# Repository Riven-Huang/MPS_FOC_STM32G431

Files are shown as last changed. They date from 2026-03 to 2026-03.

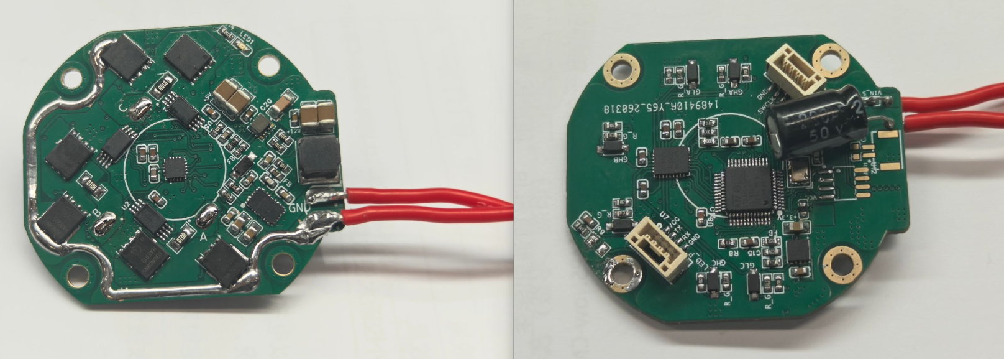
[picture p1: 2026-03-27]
docs/images/hardware_double.png

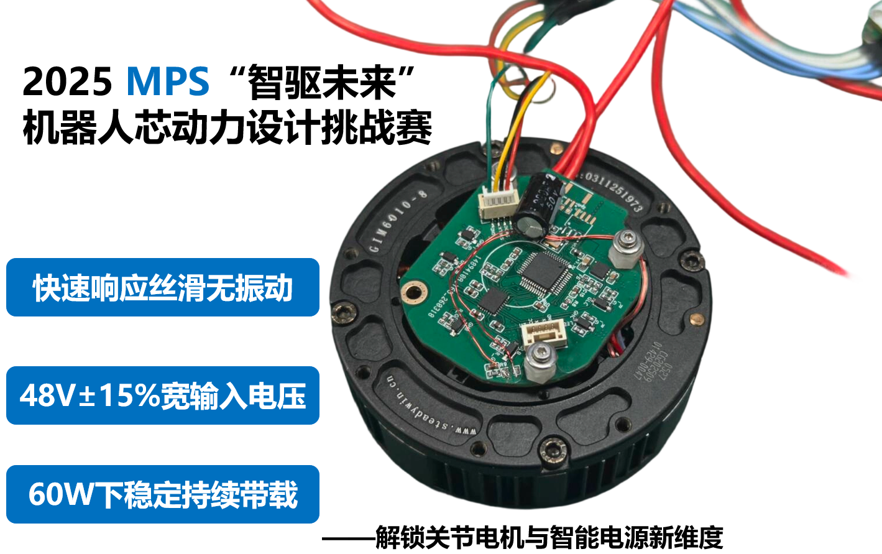
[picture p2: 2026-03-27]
docs/images/poster_done.png

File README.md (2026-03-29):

<div align="center">

# MPS-FOC STM32G431

### 开源无刷电机 FOC 控制工程 | Open-Source PMSM / BLDC FOC Project

<p>
  
  
  
  
  
</p>

</div>

> 注意，刚说明针对LCEDA项目下的V1.2版本，其余版本为F280023C下设计，未提供程序源码。V1.2为三环闭环完整的STM32G431CBT6所设计

## 目录

- [1. 项目简介](#sec-1-overview)
- [2. MPS大学计划](#sec-2-mps)
- [3. 验收测试与视频](#sec-3-test)
- [4. 硬件说明](#sec-4-hardware)
- [5. 软件架构](#sec-5-software)
- [6. 控制实现说明](#sec-6-control)
- [7. 快速开始](#sec-7-quickstart)
- [8. 项目目录](#sec-8-tree)
- [9. 已知限制与后续计划](#sec-9-plan)
- [10. 相关文件](#sec-10-files)
- [11. 许可证说明](#sec-11-license)

---

## 1. 项目简介

### 1.1 项目定位

本项目基于 `STM32G431CBT6`，面向 `PMSM / BLDC` 的三相 FOC 控制。仓库目标是提供一套可直接落到板级 bring-up 的开源实现。

适用场景：

- 板子已经打样完成，需要尽快确认“代码怎么烧录、上电后怎么先转起来”。
- 正在做自研 FOC 控制板，需要参考一套完整的“采样 -> 快环 -> 慢环 -> telemetry -> 调参”工程结构。

### 1.2 当前工程状态

当前仓库已经具备完整主链路，不是只有框架：

- 当前工程实现了所有MPS-FOC比赛中的所有测试项目，该项目为开源广场LCEDA中的**V1.2版本**(<mark>一定注意！！！</mark>)，仅仅V**1.2版本**是STM32G431制作，其余系列为TI的F280025C DSP系列下进行迭代产物。

---

## 2. MPS大学计划

### 2.1 申请说明

MPS 中国大学计划面向高校教学、科研与竞赛项目，适合本项目所用电机控制相关器件申请。若需要 `MP6539B`、`MA600A`、`MIE1W0505`、`MP4583`、`MPM3632S`、`MP20051` 等样片，可通过对应入口申请。

- 在校大学生：使用 [MPS大学计划](https://www.monolithicpower.cn/cn/support/mps-cn-university.html)
- 非在校个人开发者：使用 [MPSNOW](https://www.monolithicpower.cn/cn/support/mps-now.html)
- 申请备注：`MPS-competition-FOC`

### 2.2 二维码入口

<p align="center">
  MPS University Program QR
</p>

---

## 3. 验收测试与视频

本节将仓库内已经公开的验收项、测试视频与现有数据集中整理，便于开源发布时快速核对。当前能够直接在仓库中举证的量化结果包括：

- `48V ±15%` 宽输入电压
- `60W` 下稳定持续带载
- 一系列基础测试项
- `180W`下带载情况与热测量

### 3.1 验收测试总表

| # | 验收项目 | 参考验收标准 | 测试数据 | 数据来源 |
| --- | --- | --- | --- | --- |
| 1 | 电源输入范围测试 | `48V ±15%` 宽输入电压 | 40V-56V宽输入运行 | 视频：Test1 Power Supply  Input Voltage Range Test.mp4 |
| 2 | 启停性能测试 | 空载测试，目测电机启动是否丝滑无振动 | 见视频运行结果 | 视频：Test2 StartStop Performance.MP4 |
| 3 | 速度控制精度测试 | 目标转速100RPM、200RPM, 通过MA600A寄存器读对应速度值 | 测试报告记录：电机减速箱后出轴端 `100 rpm`下扰动`3rpm`、输出轴 `200 rpm` 下，`8rpm` | 视频：Test3 Speed Control Accuracy.MP4 |
| 4 | 位置控制精度测试 | 目标角度90°、180°, 通过MA600A寄存器读对应角度值 | 几乎无误差 | 视频：Test4 Position Control Accuracy |
| 5 | 负载输出能力测试 | 带载持续运行，可结合实际情况选择验证方式<br/> 1.通过10cm力臂实际带载2kg，验证可支持≥6A相电流<br/> 2. R+L模型模拟: 负载星型连接，每相取3Ω+200μH<br/>HSA=L, LSA=H；HSC=L, LSC=H<br/>HSB=20khz PWM 62% 占空比，LSB 与其互补； <br/>测量该条件下IOUTB或48V母线侧电流大小 | 当该项目等效功率60W等级。本仓库对于60W等级和180W等级分别进行了测试，详情可见下面说明。 | 视频：LoadTEST.MP4 |
| 6 | 负载输出能力补充测试 | 10cm力臂，2kg负载，48Vbus 265rpm下连续运行30分钟，测量电机NTC热敏电阻(10K 3950)对应阻值 | 同上 | 视频：LoadTEST.MP4 |

### 3.2 单项测试数据

3.2.1 电源输入测试

略

3.2.2 启停性能测试

略

3.2.3 速度控制精度测试



如上图所示为速度控制时的精度与扰动，图示的数据为电机出轴端之前的机械转速RPM。

3.2.4 位置控制精度



如图所示，几乎无误差

3.2.5

测试平台如下图，准备了两个一样的电机，一个电机作为驱动，另一个作为发电机，通过增程器整流输出到电子负载。



负载输出测试，如图所示。可以参考视频，在180W情况下持续带载运行(赛题要求的功率等级是60W等级)，运行2mins时温度如下图



运行8mins后，壳温来到了74℃，板上最热点为82.9℃。

---

## 4. 硬件说明

### 4.1 硬件实物图





### 4.2 硬件核心配置

| 🧩 模块  | 📦 当前实现 | 📝 说明 |
| --- | --- | --- |
| 主控 MCU | `STM32G431CBT6` | 170 MHz，带高级定时器，适合 FOC 快环  |
| PWM 输出 | `TIM1 CH1/2/3 + CH1N/2N/3N` | 中心对齐、互补输出、带死区 |
| 功率级使能  | `N_SLEEP` | 控制驱动器休眠 / 使能 |
| 故障输入 | `N_FAULT` | 当前用于驱动器故障检测 |
| 电流采样 | `ADC1_IN1 / IN3 / IN4` | 三相独立采样，注入组同步触发 |
| 母线采样 | `ADC2_IN12` | `VBUS` |
| 温度采样 | `ADC2_IN14` | `NTC` |
| 编码器 | `MA600A + SPI1` | 16-bit 绝对值角度反馈 |
| 调试串口 | `USART1 + DMA TX` | VOFA / JustFloat 波形输出 |
| 预驱动芯片  | `MP6539B` | 3 相 N+N 半桥预驱动，支持 100% 占空比 |
| 升降压芯片  | `MP4583` | 宽输入电压 DCDC，支持 48V 总线 |
| 栅极驱动供电 | `MIE1W0505` | 隔离 DC-DC，为预驱动提供隔离供电 |
| POL 供电 | `MPM3632S` | 3.3V/3A POL，为 MCU 和编码器供电  |
| 备份供电 | `MP20051` | LDO，为 MCU 待机部分供电 |

### 4.3 电机与机构默认参数

当前默认参数位于 [`program/App/motor_params.h`](program/App/motor_params.h)：

| ⚙️ 参数 | 当前值  | 说明 |
| --- | ---- | --- |
| 极对数 | `14` | `MOTOR_POLE_PAIRS` |
| 减速比 | `8`  | `MOTOR_GEAR_RATIO` |
| 编码器方向 | `-1` | `MOTOR_ENCODER_DIRECTION_SIGN` |
| 编码器安装位置 | 转子侧  | `MOTOR_ENCODER_ON_OUTPUT_SHAFT = 0` |

## 5. 软件架构

### 5.1 软件结构图

<p align="center">
  Software Architecture
</p>

### 5.2 控制流程图

<p align="center">
  Control Flow
</p>

### 5.3 代码组织

| 📁 目录 / 文件 | 🧠 职责 |
| --- | --- |
| `program/Core/` | HAL 初始化、IRQ、CubeMX 生成外设配置 |
| `program/App/program.c` | 当前真实控制主链路、快慢环调度、保护、telemetry |
| `program/App/foc_core.c` | Clarke / Park / 反 Park / SVPWM  |
| `program/App/ma600a.c` | MA600A 绝对值编码器驱动 |
| `program/App/filter.c` | 一阶低通滤波器 |
| `program/App/cli_uart.c` | VOFA / DMA 串口发送 |
| `program/App/drv_pid.c` | 通用 Q15 PI 组件，当前不在 10 kHz 热路径主链里 |
| `program/App/motor_state.c` | 状态对象与保留状态机逻辑 |
| `docs/` | 补充说明、调试文档、图像资源 |

---

## 6. 控制实现说明

### 6.1 控制流程说明：从 ADC 采样到 PWM 输出

当前工程的实际控制链路如下：

1. `TIM1` 输出中心对齐 PWM，并通过 `TRGO2 = UPDATE` 触发 `ADC1 injected`。
2. `ADC1` 一次完成 `IA / IB / IC` 三路电流采样。
3. 在 `HAL_ADCEx_InjectedConvCpltCallback()` 中读取三相原始值。
4. 启动阶段累计 `1024` 个样本，得到每相零偏。
5. 同步调度 `MA600A` 读角，更新机械角、电角度和测速窗口。
6. 原始电流码值转换为安培值，并做一阶低通。
7. 执行 `Clarke / Park`，得到 `id / iq`。
8. 位置环按 `100 Hz` 分频运行，输出机械速度参考。
9. 速度环按测速窗口更新运行，输出 `iq_ref` 或 `uq_ref`。
10. 电流环按 `10 kHz` 运行，输出 `ud_ref / uq_ref`。
11. 反 `Park` 后进入 `SVPWM`。
12. 将 `duty_a / duty_b / duty_c` 写入 `TIM1->CCR1/2/3`。

### 6.2 中断结构 / 控制周期

快环入口调用链：

```text
ADC1_2_IRQHandler
  -> HAL_ADC_IRQHandler(&hadc1)
    -> HAL_ADCEx_InjectedConvCpltCallback()
      -> program_adc_injected_conv_cplt_callback()
```

慢环入口调用链：

```text
TIM6_DAC_IRQHandler
  -> HAL_TIM_IRQHandler(&htim6)
    -> HAL_TIM_PeriodElapsedCallback()
```

当前工程对应的运行频率：

| ⏱️ 项目 | 当前值 | 触发源 / 说明 |
| --- | --- | --- |
| PWM 载波 | 约 `20 kHz`  | `TIM1 center-aligned + ARR=4249 + RCR=3` |
| 电流环 | `10 kHz` | `ADC1 injected` 完成回调 |
| 位置环 | `100 Hz` | 快环分频 |
| 速度测速窗口 | `20` 个快环样本  | `PROGRAM_SPEED_OBSERVER_WINDOW_SAMPLES`  |
| 速度环有效更新率 | 名义 `500 Hz` | 由测速窗口更新驱动 |
| 慢任务节拍 | `1 kHz` | `TIM6` 中断 + `TIM6 TRGO -> ADC2` |

慢环主要处理：

- `ADC2 + DMA` 采集 `VBUS / NTC`
- `program_task()` 在 `while(1)` 中按 `TIM6` 节拍执行后台任务和遥测输出

### 6.3 速度环与测速观测器

（内容待补充）

### 6.4 位置环实现

（内容待补充）

### 6.5 状态机与启动时序

（内容待补充）

### 6.6 Telemetry 变量设计

当前统一观测对象是：

```c
extern volatile program_telemetry_t g_program_telemetry;
```

该对象的职责不是“只拿来画波形”，而是把 bring-up 所需的事实状态统一汇总到一个对象里。这样做有两个直接好处：

- 调试器观察和 VOFA 输出共用同一套字段。
- 采样层、控制层、命令层、状态层不再散落成多个临时全局变量。

| 📊 层级 | 典型字段 | 作用 |
| ----- | --- | --- |
| 原始采样层 | `ia_raw` `ib_raw` `ic_raw` `vbus_raw` | 查 ADC、偏置和量程问题 |
| 工程量层  | `ia` `ib` `ic_meas` `id` `iq` `theta_elec` | 查控制量是否正确 |
| 命令层 | `id_ref_cmd` `iq_ref_cmd` `ud_ref_cmd` `uq_ref_cmd` | 查参考值链路是否正确传递  |
| 运行状态层 | `control_state` `driver_fault_active` `fast_loop_time_us` | 查状态机与实时性 |

如果你习惯把这个对象命名为 `g_motor_telemetry`，角色是一样的；但当前仓库实际实现以 `g_program_telemetry` 为准。

---

## 7. 快速开始

此处重点关注变量g_motor,控制参数结构体

### 7.1 开发环境

- IDE：Keil / MDK
- 工程文件：[`program/MDK-ARM/STM32G431_FOC.uvprojx`](program/MDK-ARM/STM32G431_FOC.uvprojx)
- CubeMX 工程：[`program/STM32G431_FOC.ioc`](program/STM32G431_FOC.ioc)
- 下载方式：CMSIS-DAP Debugger

### 7.2 程序上电后自动完成的内容

- `ADC1 / ADC2` 校准
- `TIM1` PWM 启动并保持 `50%` 占空比
- 三相电流零偏累计
- `ADC2 DMA` 开始采集 `VBUS / NTC`
- `MA600A` 首次读角

### 7.3 第一次跑起来的推荐配置

建议第一次出力先不要直接上速度环，而是先做开环电压测试：

```c
g_motor.current_loop_enable = 0;
g_motor.speed_loop_enable = 0;
g_motor.position_loop_enable = 0;
g_motor.ud_ref = 0.0f;
g_motor.uq_ref = 0.5f;   /* 从小值开始 */
g_motor.run_request = 1;   /*  最核心的启动信号，启动这个才开始运行发波 */
```

程序会先自动做对齐，再进入基于编码器角度的手动电压模式。

### 7.4 模式控制说明

该版本program一共有四个模式控制变量，与一个运行启动控制变量。其中每个模式变量负责一个环路，运行启动变量负责整个系统的使能。

```c
g_motor.current_loop_enable = 0; /* 是否用电流环控制，若失能则跑开环电压*/
g_motor.speed_loop_enable = 0;  /* 是否用速度环控制，若失能则单电流环或开环电压*/
g_motor.position_loop_enable = 0;/* 位置环，需使能速度环使用，否则无效果*/
g_motor.
g_motor.run_request = 1;   /*  最核心的启动信号，启动这个才开始运行发波 */
```

各个模式调试时，可以再继续看g_motor内部的ref变量，使能对应控制环的时候，需要手动给定对应的ref变量。

### 7.5 首次需要看的变量

| 👀 变量 | 正常现象 |
| --- | --- |
| `current_offset_ready` | 上电后置位 |
| `ia / ib / ic_meas` | 静止时接近 `0` |
| `i_abc_sum` | 接近 `0` |
| `ma600a_angle_rad` | 手动转动时连续变化 |
| `driver_fault_active`  | `0` |
| `fast_loop_overrun` | `0` |

### 7.6 三环由内到外的闭环调试顺序

不要跳步，建议严格按“由内到外”执行：

| 阶段 | 🎯 目标  | 🔧 推荐配置 | 👀 重点观察 |
| --- | --- | --- | --- |
| Stage 0 | 静态链路确认 | `run_request = 0` | `ia/ib/ic` `vbus` `ma600a_angle_rad` |
| Stage 1 | 验证出力方向 | 关速度环、关位置环 | `uq_ref` `theta_elec` |
| Stage 2 | 调电流环 | 开电流环，关外环 | `id` `iq` `ud_ref_cmd` `uq_ref_cmd` |
| Stage 3 | 调速度环 | 开速度环，位置环保持关闭 | `speed_ref_mech_rpm` `speed_meas_mech_rpm` |
| Stage 4 | 调位置环 | 最后再开位置环 | `position_ref_mech_rad` `position_meas_mech_rad` |

### 7.7 当前运行默认参数

以下为当前主路径实际生效的默认参数，来源于 [`program/App/program.c`](program/App/program.c)：

电流环带宽计算，可以看代码注释，当前电流环带宽为1Khz。

| 🧪 参数 | 当前值 |
| --- | --- |
| `current_kp`  | `2.5761`  |
| `current_ki`  | `4555.31` |
| `speed_kp` | `0.003` |
| `speed_ki` | `0.03` |
| `position_kp` | `3.0` |
| `position_ki` | `0.0` |
| `iq_limit` | `8.0 A` |

更详细的 bring-up 和三环调试步骤见 [`docs/quick-start.md`](docs/quick-start.md)。

---

## 8. 项目目录

```text
.
|-- README.md
|-- LICENSE
|-- circurit/                    # 原理图、器件手册、Gerber（目录名沿用当前仓库拼写）
|-- docs/
|   |-- quick-start.md           # 快速开始与三环调试说明
|   |-- figures/                 # 软件架构图、控制流程图
|   `-- images/                  # README 图片资源
|-- experiment/
|   |-- photo/                   # 波形截图、VOFA 截图、实拍图
|   |-- video/                   # 单项测试视频
|   `-- 测试报告.docx
`-- program/
    |-- STM32G431_FOC.ioc        # CubeMX 工程
    |-- Core/                    # HAL / IRQ / CubeMX 生成代码
    |-- App/                     # 控制算法与项目逻辑
    `-- MDK-ARM/                 # Keil 工程
```

---

## 9. 已知限制与后续计划

### 9.1 当前已确认的限制

- MA600A角度反馈链路，应当存在一定问题，导致速度环目前有一个波动始终存在，且1/4倍于电机机械转速，也就是2倍于电机出轴端的转速。
- 目前MA600A的反馈链路未做INL校准。

---

## 10. 相关文件

- [快速开始与三环调试文档](docs/quick-start.md)
- [软件结构图](docs/figures/software-architecture.svg)
- [控制流程图](docs/figures/control-flow.svg)
- [CubeMX 工程](program/STM32G431_FOC.ioc)
- [Keil 工程](program/MDK-ARM/STM32G431_FOC.uvprojx)
- [测试报告](experiment/%E6%B5%8B%E8%AF%95%E6%8A%A5%E5%91%8A.docx)
- [实验图片目录](experiment/photo)
- [实验视频目录](experiment/video)

---

## 11. 许可证说明

本项目基于 **GNU General Public License v3.0 (GPL 3.0)** 开源许可协议发布。

详细内容请参阅本仓库根目录下的 [`LICENSE`](LICENSE) 文件。

### 概要

- **允许**：自由使用、修改、商业衍生
- **要求**：衍生作品必须同样以 GPL 3.0 发布，并保留源码
- **禁止**：不以任何方式提供源码

### 引用方式

```text
MPS-FOC STM32G431
Copyright (C) 2026 MPS China University Program
This program is free software: you can redistribute it and/or modify
it under the terms of the GNU General Public License as published by
the Free Software Foundation, either version 3 of the License.
```

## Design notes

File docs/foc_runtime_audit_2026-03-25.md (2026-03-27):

# FOC Runtime Audit

审查日期：2026-03-25

审查范围：

- `program/App/program.c`
- `program/App/foc_core.c`
- `program/App/ma600a.c`
- `program/App/cli_uart.c`
- `program/App/motor_state.c`
- `program/App/drv_pid.c`
- `program/App/filter.c`
- `program/Core/Src/main.c`
- `program/Core/Src/adc.c`
- `program/Core/Src/tim.c`
- `program/Core/Src/spi.c`
- `program/Core/Src/usart.c`
- `program/Core/Src/stm32g4xx_it.c`

## 1. 结论摘要

- 已确认一个与“系统运行一段时间后单周期执行时间越来越长，随后速度抖动加重并最终乱转”高度一致的主因。
- 主因是编码器 PLL 的机械角 `g_encoder_pll_pos_mech_rad` 持续累加，而控制角生成路径又要对这个连续角做包角。原来的包角实现是 `while (angle >= 2pi) angle -= 2pi;` 这种与运行时间成正比的循环。电机转得越久，循环次数越多，ADC 快环耗时就越长。
- 这个问题会进一步拖慢 SPI1 编码器完成中断，因为 `ADC1_2_IRQn` 优先级是 0，而 `SPI1_IRQn` 优先级是 2。快环一旦开始超时，SPI 完成回调更难及时执行，`ma600a_read_angle()` 更容易遇到 `transfer_busy`，编码器样本间隔变大，速度估计抖动加重。
- 当前代码在 ADC 中断和 TIM6 中断里，没有发现 `HAL_Delay()`、阻塞式 `printf()`、阻塞式 SPI/ADC 轮询这种“硬阻塞”。
- 但 ADC 快环里有不少高代价操作：`sinf()`、`cosf()`、`sqrtf()`、两次 Park 相关计算、SVPWM、GPIO 写、SPI 启动、遥测结构体更新、DWT 计时。这些不是阻塞，但会实打实占用 100 us 预算。
- 当前 active path 里没有发现明显的分母为 0 风险。`dt` 不是测量出来的，而是编译期常量；速度观测器里 `sample_dt_s <= 0` 也已经做了保护。
- 当前 active path 的 float PI 积分项有硬限幅；未接入的 Q15 PI 也有硬限幅。原代码的问题不是“完全没限幅”，而是“缺少有限值保护”，一旦上游出现 NaN/Inf，会直接污染积分项并扩散。本次已补保护。

## 2. 本次确认并已处理的关键问题

### 2.1 已确认主因：包角耗时随运行时间增长

修复前的实际风险链路是：

`program_adc_injected_conv_cplt_callback()`  
-> `program_run_speed_current_control()`  
-> `program_get_control_elec_angle_rad()`  
-> `program_get_encoder_pll_aligned_elec_angle_rad()`  
-> `motor_params_rotor_mech_to_elec_rad(g_encoder_pll_pos_mech_rad)`  
-> `motor_params_wrap_angle_rad()`

问题本质：

- `g_encoder_pll_pos_mech_rad` 是连续累加量。
- 连续累加量越大，`while(angle >= 2pi)` 的减法次数越多。
- 这个包角函数在 10 kHz ADC 快环里被频繁调用。
- 所以单周期执行时间会随运行时间持续增长。

这正好解释了你观察到的现象：

- 刚上电能跑。
- 跑一段时间后单周期耗时越来越长。
- SPI 编码器更新开始掉拍。
- 速度观测抖动变大。
- 闭环角度和电流环一起失稳，最终乱转。

本次已处理：

- `program/App/program.c:93` 新增常数时间包角 `program_wrap_angle_0_2pi()`
- `program/App/program.c:270` 新增 `program_renormalize_encoder_observer()`，周期性把 PLL 连续角归一化，避免 float 连续增大
- `program/App/foc_core.c:32` 把 `foc_core_wrap_angle()` 改成常数时间
- `program/App/motor_params.h:12` 把 `motor_params_wrap_angle_rad()` 改成常数时间

### 2.2 已确认次级问题：连续机械角长期不归一化会带来 float 精度恶化

即使把 `while` 改掉，`g_encoder_continuous_mech_rad` 和 `g_encoder_pll_pos_mech_rad` 如果一直增长，float 有效分辨率仍会越来越差。

后果：

- 相位误差 `phase_error_rad = continuous - pll_pos` 的有效精度下降
- PLL 速度估计变抖
- 速度环输入抖动加重

本次已在 `program/App/program.c:270` 加入归一化，避免连续角无限增大。

### 2.3 已确认 NaN 风险点：原 float PI 有硬限幅，但没有有限值保护

当前 float PI 在 `program/App/program.c:217`，积分项限幅在：

- `program/App/program.c:249`
- `program/App/program.c:250`

未接入的 Q15 PI 在 `program/App/drv_pid.c:105`，积分项限幅在：

- `program/App/drv_pid.c:123`
- `program/App/drv_pid.c:128`

结论：

- 积分项并不是“完全没硬限幅”。
- 但原来只做大小比较，不做 `isfinite()` 检查。
- 一旦某次上游输入已经是 NaN，比较表达式会全部失效，积分器会被直接写成 NaN。

本次已在 `program/App/program.c:231` 到 `program/App/program.c:245` 增加有限值保护。

## 3. 核心函数执行频率、执行方式、执行上下文

前提时钟：

- `.ioc` 指定 HSE 为 8 MHz：`program/STM32G431_FOC.ioc:271`
- HAL 配置里的 `HSE_VALUE` 也是 8 MHz：`program/Core/Inc/stm32g4xx_hal_conf.h:118`
- 主时钟 PLL 配置在 `program/Core/Src/main.c:137` 到 `program/Core/Src/main.c:160`
- 结合 `PLLM=2, PLLN=85, PLLR=2`，系统时钟是 170 MHz

| 函数/链路 | 频率 | 执行方式 | 执行上下文 | 说明 |
| --- | --- | --- | --- | --- |
| `main()` -> `while(1)` -> `program_task()` | while 持续轮询，实际 1 kHz 生效 | 轮询 | 主循环 | 入口在 `program/Core/Src/main.c:111` 到 `program/Core/Src/main.c:116`，真正 1 ms 节拍在 `program/App/program.c:979` 到 `program/App/program.c:992` |
| `TIM6` 基准 | 1 kHz | 定时器更新中断 | `TIM6_DAC_IRQn` | `PSC=169, ARR=999`，见 `program/Core/Src/tim.c:128` 到 `program/Core/Src/tim.c:139` |
| `program_tim_period_elapsed_callback()` | 1 kHz | 中断回调 | TIM6 中断 | 只做 `g_tim6_tick_ms++`，见 `program/App/program.c:1000` 到 `program/App/program.c:1005` |
| `ADC2` regular + DMA | 1 kHz | TIM6 TRGO 触发 + DMA 环形搬运 | 外设硬件 + while 后台读取 | `ADC2` 由 `TIM6_TRGO` 触发，见 `program/Core/Src/adc.c:133` 到 `program/Core/Src/adc.c:147`；后台消费在 `program/App/program.c:990` |
| `program_update_measurements()` | 1 kHz | 直接函数调用 | `program_task()` | 读取 `VBUS/NTC` DMA 结果，定义在 `program/App/program.c:842`，调用在 `program/App/program.c:990` |
| `program_send_wave_if_needed()` | 50 Hz | 直接函数调用 + UART DMA | `program_task()` | 20 ms 节流，见 `program/App/program.c:898` |
| `TIM1` PWM | 20 kHz 载波 | 硬件 PWM | TIM1 | `CenterAligned1, ARR=4249`，见 `program/Core/Src/tim.c:46` 到 `program/Core/Src/tim.c:68` |
| `TIM1_TRGO2` -> `ADC1` 注入组 | 10 kHz | 硬件触发 | TIM1 -> ADC1 | `TRGO2=UPDATE` 且 `RepetitionCounter=3`，对应 10 kHz 电流采样节拍 |
| `program_adc_injected_conv_cplt_callback()` | 10 kHz | HAL injected ADC 完成回调 | `ADC1_2_IRQn` | 快环总入口，见 `program/App/program.c:1022` 到 `program/App/program.c:1077` |
| `program_update_encoder_measurements()` | 名义 10 kHz | 直接函数调用 | ADC 快环 | 用的是“上一次 SPI 已完成”的编码器样本，见 `program/App/program.c:863` |
| `ma600a_read_angle()` | 名义 10 kHz 发起 | 非阻塞 SPI 启动 | ADC 快环里发起，SPI 中断里完成 | 启动在 `program/App/ma600a.c:88` 到 `program/App/ma600a.c:105` |
| `HAL_SPI_TxRxCpltCallback()` -> `ma600a_spi_txrx_cplt()` | 名义 10 kHz 完成 | SPI 中断 | `SPI1_IRQn` | 完成回调桥接在 `program/App/program.c:1116`，SPI 优先级见 `program/Core/Src/spi.c:89` 到 `program/Core/Src/spi.c:91` |
| `program_update_speed_measurement()` | 名义 10 kHz，取决于新编码器样本是否到达 | 直接函数调用 | ADC 快环 | 仅当 `sample_counter` 变化时执行，见 `program/App/program.c:496` |
| `program_update_speed_loop()` | 每 100 us 被调用一次，但 PI 真正每 1 ms 执行一次 | 分频调度 | ADC 快环 | `PROGRAM_SPEED_LOOP_DIVIDER=10`，见 `program/App/program.c:30`、`program/App/program.c:560` 到 `program/App/program.c:582` |
| `program_update_current_feedback_from_raw()` | 10 kHz | 直接函数调用 | ADC 快环 | 完成电流换算、Clarke、Park，见 `program/App/program.c:588` |
| `program_run_current_loop()` | 10 kHz | 直接函数调用 | ADC 快环 | 电流 PI + 电压限幅 + FOC 输出，见 `program/App/program.c:632` |
| `foc_core_run_voltage_open_loop()` | 10 kHz | 直接函数调用 | ADC 快环 | 尽管名字叫 open loop，当前也被闭环电流环复用来完成反 Park + SVPWM，见 `program/App/foc_core.c:239` |
| `program_apply_svpwm_to_tim1()` | 10 kHz | 直接寄存器写 CCR | ADC 快环 | 更新 PWM 比较值，见 `program/App/program.c:382` 到 `program/App/program.c:411` |

## 4. 中断路径里是否存在耗时阻塞操作

### 4.1 ADC 快环里没有发现“硬阻塞”

10 kHz 快环入口在 `program/App/program.c:1022` 到 `program/App/program.c:1077`。

我没有在这个路径里发现下面这些问题：

- `HAL_Delay()`
- 阻塞式 UART 打印
- 阻塞式 SPI 读写
- `while(flag == 0)` 这种等待外设完成的轮询

### 4.2 但快环里存在一组明显的高开销操作

这些操作都在快环里，会稳定占预算：

- `HAL_ADCEx_InjectedGetValue()` 三次：`program/App/program.c:983` 到 `program/App/program.c:985`
- 发起一次 SPI 非阻塞传输：`program/App/program.c:1005` 到 `program/App/program.c:1007`，底层调用在 `program/App/ma600a.c:105`
- 电流反馈里的 `sinf()/cosf()`：`program/App/program.c:622` 到 `program/App/program.c:623`
- FOC 输出里的 `sinf()/cosf()`：`program/App/foc_core.c:126` 到 `program/App/foc_core.c:127`
- 电压矢量模长 `sqrtf()`：`program/App/program.c:661`
- 每拍都在写 `N_SLEEP`：`program/App/program.c:459`
- 每拍都更新调试遥测：`program_run_speed_current_control()` 内最终调用 `program_update_debug_telemetry()`
- 每拍都做 DWT 周期计时更新：`program/App/program.c:1018` 到 `program/App/program.c:1019`

结论：

- 当前不是“中断里有阻塞式死等”。
- 当前是“中断里有过多数学运算和调试逻辑，而且之前还有一个会随时间增长的包角循环”。

## 5. 除法、dt、积分项、NaN 审查

### 5.1 当前 active path 的除法点

| 位置 | 表达式 | 风险结论 |
| --- | --- | --- |
| `program/App/program.c:477` | `sense_voltage / (gain * shunt)` | 当前常量 `20 * 0.01`，分母固定非 0 |
| `program/App/program.c:493` | `... / PROGRAM_VBUS_R_DOWN_OHM`  | 当前常量 `10000`，非 0 |
| `program/App/program.c:539` | `mech_delta_rad / sample_dt_s` | 已有 `sample_dt_s <= 0` 保护，见 `program/App/program.c:533` 到 `program/App/program.c:535` |
| `program/App/program.c:661` 到 `program/App/program.c:664` | `v_limit / v_mag` | 已有 `v_mag > 0` 保护 |
| `program/App/foc_core.c:195` 到 `program/App/foc_core.c:204` | `v_alpha/vbus` 等 | 已有 `vbus < 1` 保护，低电压时直接输出中心占空比 |
| `program/App/program.c:305` 到 `program/App/program.c:328` | `1000000 / SystemCoreClock` | 已有 `SystemCoreClock == 0` 保护 |

### 5.2 `dt = 0` 风险

结论：

- 当前快环 `dt` 是编译期常量 `PROGRAM_FAST_LOOP_DT_S = 1 / 10000`，见 `program/App/program.c:22` 到 `program/App/program.c:24`
- 当前速度环 `dt` 是编译期常量 `PROGRAM_SPEED_LOOP_DT_S = 10 * 100 us = 1 ms`，见 `program/App/program.c:30` 到 `program/App/program.c:31`
- 也就是说，当前 PI 本身不存在“通过测时间得到 dt，结果某次 dt=0”的问题
- 真正动态的 `dt` 只出现在编码器速度观测器里，且已有 `sample_dt_s <= 0` 返回保护

### 5.3 PID/PI 积分项是否缺少硬限幅

结论：

- active path 的 float PI：有硬限幅，不缺
- 未接入的 Q15 PI：也有硬限幅，不缺

具体位置：

- float PI：`program/App/program.c:249` 到 `program/App/program.c:250`
- Q15 PI：`program/App/drv_pid.c:126` 到 `program/App/drv_pid.c:128`

真实问题是：

- 原来的 float PI 没有 `isfinite()` 防护
- 一旦上游已经出现 NaN，积分项会被直接写坏
- 本次已在 `program/App/program.c:231` 到 `program/App/program.c:245` 加入保护

## 6. 速度环是否和电流环解耦

结论：

- 逻辑上“解耦了频率”
- 但“没有解耦执行上下文”

具体表现：

- 电流环是 10 kHz，入口在 ADC 注入组完成中断
- 速度环通过 `PROGRAM_SPEED_LOOP_DIVIDER = 10` 做了 10 分频，所以 PI 真正每 1 ms 执行一次，见 `program/App/program.c:30`、`program/App/program.c:571` 到 `program/App/program.c:581`
- 但是速度环仍然放在同一个 ADC 快环 ISR 里

这意味着：

- 速度环不会每 100 us 都做 PI
- 但它仍和电流环共用同一个 100 us 中断预算
- 只要快环过重，速度环也会被连带抖动

所以这里是“频率解耦了，时间隔离没有做”。

## 7. 其他潜在问题

### 7.1 SPI 编码器采样并不是完全独立时基

编码器读取方式是：

- 在 ADC 快环里发起 `HAL_SPI_TransmitReceive_IT()`：`program/App/program.c:1005` 到 `program/App/program.c:1007`
- 在 `SPI1_IRQn` 里完成回调：`program/App/program.c:1116`

注意优先级：

- `ADC1_2_IRQn` 优先级 0：`program/Core/Src/adc.c:220` 到 `program/Core/Src/adc.c:222`
- `SPI1_IRQn` 优先级 2：`program/Core/Src/spi.c:89` 到 `program/Core/Src/spi.c:91`

因此：

- SPI 完成中断不能抢占 ADC 快环
- 快环一旦拖长，SPI 完成回调就会延后
- 下一个 ADC 周期里 `ma600a_read_angle()` 更容易遇到 `transfer_busy`
- 速度观测 `sample_delta_count` 会变大，速度估计抖动明显

### 7.2 `program_set_power_stage_enable()` 每个快环周期都在写一次 GPIO

位置：

- `program/App/program.c:454` 到 `program/App/program.c:461`

现状：

- 即便状态没变，闭环期间也会每 100 us 写一次 `N_SLEEP`

这不是导致崩溃的主因，但属于不必要的快环负担。

### 7.3 共享 ADC 中断里每次都调用了 `HAL_ADC_IRQHandler(&hadc2)`

位置：

- `program/Core/Src/stm32g4xx_it.c:238` 到 `program/Core/Src/stm32g4xx_it.c:244`

影响：

- 这是常量额外开销，不会随时间增长
- 但在 10 kHz 快环里属于可以省掉的固定成本

### 7.4 `cli_uart_send_text()` 是阻塞式串口发送

位置：

- 定义：`program/App/cli_uart.c:40`
- 阻塞发送：`program/App/cli_uart.c:57`

当前结论：

- 当前 active path 没有调用它
- 现在波形发送走的是 DMA：`program/App/cli_uart.c:66` 到 `program/App/cli_uart.c:91`
- 如果后续有人把 `cli_uart_send_text()` 放进快环或中断，会直接引入毫秒级阻塞

### 7.5 `motor_state_task()` 不是当前实际控制路径

位置：

- `program/App/motor_state.c:55`

说明：

- 当前真实控制闭环不走它
- 当前真实控制入口是 `program_adc_injected_conv_cplt_callback()`
- `motor_state.c` 里的注释“由 `program_task()` 1 kHz 调用”现在已经不是实际运行方式，容易误导后续维护

## 8. 本次代码修改

本次已直接修改以下文件：

- `program/App/program.c`
- `program/App/foc_core.c`
- `program/App/motor_params.h`

修改内容：

- 把包角从 `while` 循环改成常数时间实现
- 对编码器 PLL 连续角做归一化，避免连续增长
- 给 float PI 增加有限值保护，降低 NaN 污染风险

## 9. 推荐的下一步排查顺序

建议按下面顺序验证：

1. 先观察 `fast_loop_time_us` 和 `fast_loop_overrun_count` 是否还会随运行时间持续增长。
2. 再观察 `ma600a.sample_counter` 是否仍会周期性掉拍，或者 `speed_loop_ready` 是否会反复丢失。
3. 再看 `speed_meas_mech_rad_s`、`iq_ref_cmd`、`iq` 三个量是否仍有明显抖动。
4. 如果快环时间已经稳定但速度仍抖，下一步优先减少快环里的调试负担：把部分遥测更新移到 1 kHz 后台，把 `N_SLEEP` 改成只在状态变化时写。
5. 如果还要继续压缩快环时间，下一步应考虑减少 `sinf/cosf/sqrtf` 次数，或者利用 STM32G4 的 CORDIC/FM AC 外设。

## 10. 总结

这份代码里最关键的问题不是“中断里有一个显式阻塞函数”，而是“快环里存在一个与运行时间成正比的包角算法”，它会把 10 kHz 电流环逐渐拖慢，并进一步连带编码器 SPI 更新和速度观测抖动，最终表现成你现在看到的“先抖，再乱转，再宕机”。

这个问题已经在代码里做了针对性修正。当前剩余更像是“快环负担偏重”和“速度环虽然分频了，但仍和电流环共用同一个 ISR 预算”的工程优化问题，而不是同级别的致命逻辑错误。

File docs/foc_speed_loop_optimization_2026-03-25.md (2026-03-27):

# FOC Speed Loop Optimization Follow-Up

审查日期: 2026-03-25

## 1. 这次改了什么

这次没有改换相角主链，也没有改电流环 PI 主结构，重点只放在速度观测和速度环入口上。

原来的速度链路是:

- 每个新编码器样本都进一次 `program_update_speed_measurement()`
- 速度估算内部使用位置 PLL
- PLL 输出再进一阶低通
- 速度 PI 由固定 10 分频计数器触发

这个结构在能转起来以后仍然容易出现两个问题:

- 低速时单样本角度增量太小，编码器量化误差会直接污染速度估计
- 即使这一次没有新速度信息，固定分频到了，速度 PI 还是会拿旧速度值算一次

这次改成了更直接的结构:

- 先把机械角累加成连续角
- 每累计 `10` 个编码器样本，再做一次窗口差分测速
- 窗口差分的原始速度再进一阶低通
- 只有当新速度估计真正更新后，速度 PI 才执行一次
- 速度 PI 的 `dt` 不再硬写死 1 ms，而是使用这次测速窗口的实际时间

这更接近你那个 DSP 参考工程的“差分测速 + 低通”思路，但保留了当前 STM32 工程的电流环结构。

## 2. 这次调整的默认参数

位置: `program/App/program.c`

- `PROGRAM_SPEED_OBSERVER_WINDOW_SAMPLES = 10`
- `PROGRAM_SPEED_MEAS_LPF_CUTOFF_HZ = 150.0f`
- `PROGRAM_DEFAULT_SPEED_KP = 0.03f`
- `PROGRAM_DEFAULT_SPEED_KI = 0.30f`

含义:

- 速度估计名义更新率从“每个编码器样本”收敛到“约 1 kHz”
- 低速量化噪声先靠窗口差分基线压一轮，再靠 150 Hz LPF 压一轮
- 默认速度 PI 比之前保守，减少 `iq_ref_cmd` 被测速噪声带着抖

## 3. 核心函数频率和执行位置

| 运算 / 函数 | 名义频率 | 真正执行方式 | 执行上下文 |
| --- | --- | --- | --- |
| `program_adc_injected_conv_cplt_callback()` | 10 kHz | 每次 ADC1 injected 完成直接执行 | ADC 中断 |
| `ma600a_read_angle()` | 10 kHz 发起 | 非阻塞启动一次 SPI 传输 | ADC 中断 |
| `HAL_SPI_TxRxCpltCallback()` -> `ma600a_spi_txrx_cplt()` | 接近 10 kHz | SPI 完成中断回调 | SPI 中断 |
| `program_update_speed_measurement()` | 每次新编码器样本到达时调用 | 直接函数调用 | ADC 中断 |
| 窗口差分测速结果更新 | 名义约 1 kHz | 每累计 10 个编码器样本才更新一次 | `program_update_speed_measurement()` 内 |
| `program_update_speed_loop()` | 每个快环都被调用 | 只有新速度样本 ready 时 PI 才真的执行 | ADC 中断 |
| `program_run_current_loop()` | 10 kHz | 每次快环直接执行 | ADC 中断 |
| `program_task()` | while 持续轮询，实际约 1 kHz | 由 TIM6 1 ms 节拍放行 | `while(1)` |

重点:

- 速度环仍然和电流环共用同一个 ADC ISR 上下文
- 但这次已经把“速度 PI 触发条件”从固定分频改成了“新速度样本触发”
- 因此 `iq_ref_cmd` 不会再拿旧速度值空算

## 4. 这次新增的调试量

位置: `program/App/program.h`

- `ma600a_sample_counter`
- `speed_observer_window_samples`
- `speed_meas_raw_mech_rad_s`
- `speed_meas_raw_mech_rpm`
- `speed_error_mech_rad_s`
- `speed_loop_dt_s`

建议重点抓下面这些量:

- `speed_ref_mech_applied_rad_s`
- `speed_meas_raw_mech_rad_s`
- `speed_meas_mech_rad_s`
- `speed_error_mech_rad_s`
- `iq_ref_cmd`
- `iq_ref_applied_cmd`
- `iq`
- `uq_ref_cmd`
- `ma600a_sample_counter`
- `speed_loop_dt_s`
- `fast_loop_time_us`
- `fast_loop_overrun_count`

## 5. 如何 debug

先看测速链是不是稳:

- 如果 `speed_meas_raw_mech_rad_s` 很毛，但 `speed_meas_mech_rad_s` 已经平很多，说明新窗口测速已经起作用
- 如果 `speed_loop_dt_s` 长期稳定在约 `0.001 s`，说明编码器样本节拍基本稳定
- 如果 `speed_loop_dt_s` 经常跳大，先查 SPI 更新掉拍或中断抢占

再看速度 PI 有没有还在抖:

- 如果 `speed_error_mech_rad_s` 很小但 `iq_ref_cmd` 仍来回摆，说明速度 PI 还偏激进
- 如果 `iq_ref_cmd` 抖，但 `iq_ref_applied_cmd` 明显更平，说明当前主要是速度指令抖动，电流参考限速已经在帮你兜底
- 如果 `iq_ref_applied_cmd` 和 `iq` 也一起剧烈抖，说明机械上看到的抖动是真实转矩抖动，不是单纯显示噪声

最后看快环预算:

- `fast_loop_time_us` 应稳定小于 `100 us`
- `fast_loop_overrun_count` 不能持续增长

## 6. 如果你上板后还抖，下一步优先怎么调

先按这个顺序调，不要同时乱动:

1. 先看 `speed_meas_raw_mech_rad_s` 和 `speed_meas_mech_rad_s`
2. 如果原始测速还是很毛，把 `PROGRAM_SPEED_OBSERVER_WINDOW_SAMPLES` 从 `10` 提到 `12` 或 `16`
3. 如果过滤后速度还毛，可以把 `PROGRAM_SPEED_MEAS_LPF_CUTOFF_HZ` 从 `150` 往下收
4. 如果速度已经稳了但闭环还是抽，把 `speed_kp` 再降一点
5. 最后再决定要不要继续降 `speed_ki`

不建议一开始就先砍电流环，当前问题的主矛盾不在电流环带宽，而在速度观测输入和速度环触发方式。

## 7. 这次修改的边界

这次仍然没有做下面这些更激进的动作:

- 没把速度环挪到后台慢任务
- 没对 `iq_ref_cmd` 额外再套一层速度环专用 LPF
- 没做速度误差死区
- 没改 VOFA 默认发送通道定义

原因是先把观测链路和速度 PI 触发链路理顺，再决定下一刀切哪里，风险更低。

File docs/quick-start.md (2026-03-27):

# 快速开始与三环调试

这份文档默认你已经拿到同款板子，目标是尽快完成：

1. 上电自检
2. 编码器/电流采样确认
3. 第一次稳定出力
4. 电流环调试
5. 速度环调试
6. 位置环调试

如果你只想看项目概览，请先看根目录 [`README.md`](../README.md)。

## 1. 首次上电前检查

建议首次 bring-up 满足以下前提：

- 电机空载
- 电源限流
- ST-Link 在线
- 调试器可直接修改全局变量
- 如果要看串口波形，VOFA 已准备好并选择 JustFloat 协议

### 建议加入 Watch Window 的变量

第一组看硬件链路是否正常：

- `g_program_telemetry.current_offset_ready`
- `g_program_telemetry.ia`
- `g_program_telemetry.ib`
- `g_program_telemetry.ic_meas`
- `g_program_telemetry.i_abc_sum`
- `g_program_telemetry.vbus`
- `g_program_telemetry.ma600a_angle_rad`
- `g_program_telemetry.driver_fault_active`

第二组看控制链是否已经接上：

- `g_program_telemetry.theta_elec`
- `g_program_telemetry.id`
- `g_program_telemetry.iq`
- `g_program_telemetry.duty_a`
- `g_program_telemetry.duty_b`
- `g_program_telemetry.duty_c`
- `g_program_telemetry.fast_loop_time_us`
- `g_program_telemetry.fast_loop_overrun`

第三组看给定和环路状态：

- `g_motor.run_request`
- `g_motor.current_loop_enable`
- `g_motor.speed_loop_enable`
- `g_motor.position_loop_enable`
- `g_motor.id_ref`
- `g_motor.iq_ref`
- `g_motor.ud_ref`
- `g_motor.uq_ref`
- `g_motor.speed_ref_mech_rpm`
- `g_motor.position_ref_mech_rad`

## 2. 烧录与静态启动

### 烧录

- 打开 [`program/MDK-ARM/STM32G431_FOC.uvprojx`](../program/MDK-ARM/STM32G431_FOC.uvprojx)
- 编译并下载
- 复位后暂停在主循环或直接在线观察

### 启动后程序会自动完成的事情

无需手动参与，代码会先完成：

- `ADC1` 校准
- `ADC2` 校准
- TIM1 PWM 启动并保持 50% 占空比
- `ADC1 injected` 开始三相电流零偏统计
- `ADC2 DMA` 开始 `VBUS / NTC` 采样
- MA600A 首次角度读取

### 静态检查通过标准

在 `run_request = 0` 时，先确认：

| 检查项 | 期望现象 |
| --- | --- |
| `current_offset_ready` | 上电约 100 ms 后变成 `1` |
| `ia / ib / ic_meas` | 静止时接近 `0 A` |
| `i_abc_sum` | 接近 `0` |
| `vbus` | 与实际母线电压同量级 |
| `ma600a_angle_rad` | 手动转电机时连续变化 |
| `driver_fault_active`  | `0` |
| `fast_loop_overrun` | `0` |

如果这里都不正常，不要进入闭环调试。

## 3. 第一次稳定出力

第一次出力的目标不是追求速度精度，而是确认：

- 编码器方向正确
- 电角度零位对齐正确
- `uq` 正方向确实输出正扭矩
- 功率级使能链路正确

### 推荐配置

先设置：

- `g_motor.current_loop_enable = 0`
- `g_motor.speed_loop_enable = 0`
- `g_motor.position_loop_enable = 0`
- `g_motor.ud_ref = 0.0f`
- `g_motor.uq_ref = 0.5f`
- `g_motor.run_request = 1`

### 程序会自动发生什么

1. 功率级先保持关闭
2. 对齐阶段用固定 `d` 轴电压锁定转子
3. 对齐保持 `8000` 个快环节拍，约 `0.8 s`
4. 在对齐末段平均编码器电角度，计算 `encoder_elec_offset_rad`
5. 对齐完成后，进入基于编码器角度的手动 `ud/uq` 电压模式

### 正常现象

- `control_state` 先进入对齐态，再进入闭环态
- `encoder_align_done = 1`
- `theta_elec` 连续
- 电机开始平稳出力
- 小幅调 `uq_ref`，转矩方向和大小随之变化

### 如果异常

| 现象 | 优先排查 |
| --- | --- |
| 一上电就抖动或尖叫 | 电流极性、编码器方向、极对数 |
| 对齐后完全不出力 | `N_SLEEP`、`driver_fault_active`、`ma600a_angle_valid` |
| `id` 很大、`iq` 很小 | 零位对齐错误、编码器方向错误 |
| 反向出力 | `MOTOR_ENCODER_DIRECTION_SIGN` 或 `PROGRAM_CURRENT_SIGN_*` |

## 4. 电流环调试

确认电压模式出力方向正确后，再进入电流环。

### 建议初始配置

- `g_motor.current_loop_enable = 1`
- `g_motor.speed_loop_enable = 0`
- `g_motor.position_loop_enable = 0`
- `g_motor.id_ref = 0.0f`
- `g_motor.iq_ref = 0.1f` 到 `0.3f`
- `g_motor.iq_limit = 0.3f` 到 `0.5f`

### 当前电流环结构

- 电流反馈：`id / iq`
- PI 输出：`ud_ref / uq_ref`
- 积分器：`id_integral_v / iq_integral_v`
- 电压上限：`PROGRAM_VOLTAGE_LIMIT_RATIO * vbus`
- 参考斜坡：`PROGRAM_CURRENT_REF_RAMP_A_PER_S`

### 先看哪些量

- `g_program_telemetry.id`
- `g_program_telemetry.iq`
- `g_program_telemetry.id_ref_cmd`
- `g_program_telemetry.iq_ref_cmd`
- `g_program_telemetry.id_ref_applied_cmd`
- `g_program_telemetry.iq_ref_applied_cmd`
- `g_program_telemetry.ud_ref_cmd`
- `g_program_telemetry.uq_ref_cmd`
- `g_program_telemetry.voltage_limit_v`

### 调参顺序

1. 保持 `id_ref = 0`
2. 小步进给 `iq_ref`
3. 先调 `current_kp`，让 `iq` 能快速跟随但不明显振荡
4. 再加 `current_ki`，去掉稳态误差
5. 最后检查 `id` 是否仍能保持在 `0` 附近

### 当前默认参数

- `current_kp = 2.5761`
- `current_ki = 4555.31`

这组值只适用于当前板子、电流采样链和默认快环频率，换电机后不要直接照搬。

## 5. 速度环调试

当前速度环不是固定定时器硬中断，而是跟随测速窗口更新。

### 当前实现特征

- 编码器每次新样本到来都会更新连续机械角
- 每累计 `20` 个快环样本更新一次速度
- 名义速度环节拍约 `500 Hz`
- 速度测量一阶低通默认截止频率 `150 Hz`

### 建议配置

- `g_motor.current_loop_enable = 1`
- `g_motor.speed_loop_enable = 1`
- `g_motor.position_loop_enable = 0`
- `g_motor.iq_limit` 先限制在安全范围
- `g_motor.speed_ref_mech_rpm` 从小值开始

### 优先观察

- `g_program_telemetry.speed_ref_mech_rpm`
- `g_program_telemetry.speed_ref_mech_applied_rpm`
- `g_program_telemetry.speed_meas_raw_mech_rpm`
- `g_program_telemetry.speed_meas_mech_rpm`
- `g_program_telemetry.speed_loop_dt_s`
- `g_program_telemetry.iq_ref_cmd`

### 调参建议

1. 先用较小 `speed_ref_mech_rpm` 验证方向
2. 先调 `speed_kp`
3. 再逐步增加 `speed_ki`
4. `iq_limit` 是速度环最重要的安全夹紧量，不要一开始就放大

### 当前默认参数

- `speed_kp = 0.003`
- `speed_ki = 0.03`

## 6. 位置环调试

位置环按 `100 Hz` 运行，并且工作在输出轴坐标系。

### 当前实现特征

- `position_ref_mech_rad` 是输出轴目标位置
- `position_meas_mech_rad` 是输出轴实际位置
- 位置环输出的是“输出轴速度命令”
- 输出轴速度命令再乘以 `MOTOR_GEAR_RATIO`，送入转子侧速度环

### 建议配置

- `g_motor.current_loop_enable = 1`
- `g_motor.speed_loop_enable = 1`
- `g_motor.position_loop_enable = 1`
- `g_motor.position_speed_limit_mech_rad_s` 先设置小一些
- `g_motor.position_ref_mech_rad` 小步进变化

### 调参顺序

1. 先保证速度环足够稳定
2. `position_ki` 先保持 `0`
3. 逐步增加 `position_kp`
4. 只有在需要消除静差时，再小心增加 `position_ki`

### 当前默认参数

- `position_kp = 8.0`
- `position_ki = 0.0`

## 7. 运行中切换环路时要知道的事情

当前工程在模式切换时，会自动清理相关积分器和参考斜坡：

- 切换位置环时，会 reset 位置环、速度环和速度参考斜坡
- 切换电流环时，会 reset 速度环和电流环
- `run_request = 0` 时，会关闭功率级并清零各环状态

所以：

- 不要把切换前的波形直接当成切换后的调参依据
- 切环后先重新观察积分量是否被正确拉回

## 8. 移植时必须确认的参数

### 电机参数

修改 [`program/App/motor_params.h`](../program/App/motor_params.h)：

- `MOTOR_POLE_PAIRS`
- `MOTOR_GEAR_RATIO`
- `MOTOR_ENCODER_DIRECTION_SIGN`
- `MOTOR_ENCODER_ON_OUTPUT_SHAFT`

### 采样链参数

修改 [`program/App/program.c`](../program/App/program.c)：

- `PROGRAM_SHUNT_RESISTOR_OHM`
- `PROGRAM_CURRENT_SENSE_GAIN`
- `PROGRAM_VBUS_R_UP_OHM`
- `PROGRAM_VBUS_R_DOWN_OHM`
- `PROGRAM_CURRENT_SIGN_IA`
- `PROGRAM_CURRENT_SIGN_IB`
- `PROGRAM_CURRENT_SIGN_IC`

### 外设配置

修改 [`program/STM32G431_FOC.ioc`](../program/STM32G431_FOC.ioc)：

- PWM 管脚
- ADC 通道
- SPI 模式与速度
- 串口引脚与波特率

## 9. 常见故障定位

### `current_offset_ready` 长时间不置位

优先检查：

- TIM1 是否真的启动
- `ADC1 injected` 是否被 `TIM1_TRGO2` 触发
- ADC1 中断是否正常进入

### `ma600a_angle_valid = 0`

优先检查：

- SPI1 模式是否仍为 `CPOL=HIGH, CPHA=2EDGE`
- `ENC_CS` 是否正确拉低拉高
- 编码器供电是否稳定

### `id` 明显偏大

优先检查：

- 编码器方向
- 电角度零位偏移
- `MOTOR_POLE_PAIRS`
- 电流零偏是否准确

### `fast_loop_overrun = 1`

优先检查：

- 串口/调试输出是否过多
- 是否在快环里加入了额外阻塞逻辑
- SPI 角度读取是否需要改成更轻量的方式

## 10. 建议的调试节奏

如果你的目标是“当天先转起来”，推荐最短路径：

1. 只看静态零偏和编码器角度
2. 手动电压模式确认扭矩方向
3. 电流环小电流闭合
4. 速度环小转速闭合
5. 最后再上位置环

不要一边改硬件参数，一边同时调三环。先把一个环关死，只让一个环说了算，效率最高。

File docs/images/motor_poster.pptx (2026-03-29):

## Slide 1

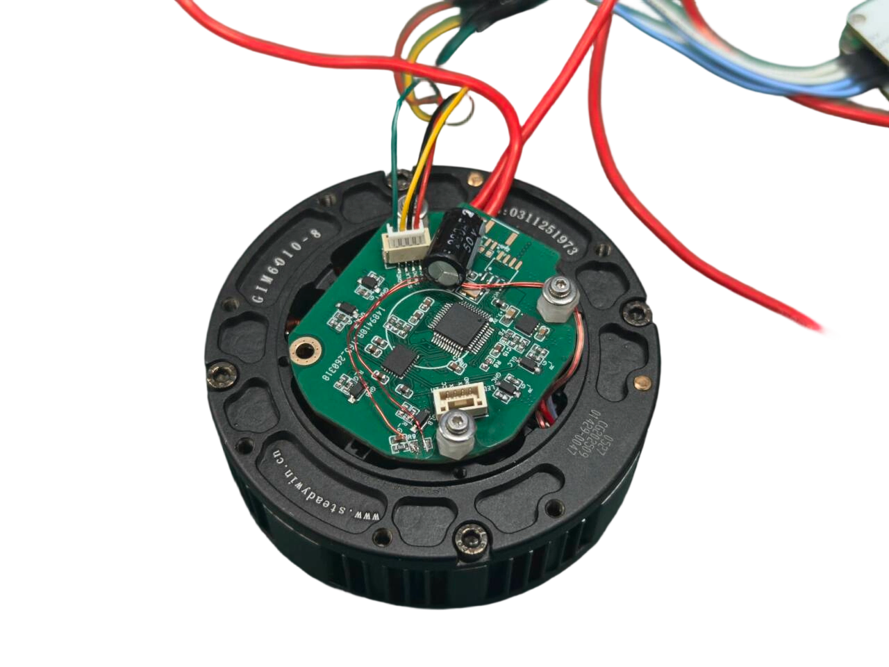
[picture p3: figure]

——解锁关节电机与智能电源新维度

2025 MPS“智驱未来”
机器人芯动力设计挑战赛

快速响应丝滑无振动

48V±15%宽输入电压

60W下稳定持续带载

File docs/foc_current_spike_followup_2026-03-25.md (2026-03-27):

# FOC Current Loop Spike Follow-Up

审查日期: 2026-03-25

## 1. 现象对应的代码根因

当前电流环本体已经能跟踪 `iq_ref`，但仍然存在“偶发尖峰”风险，主要来自两类输入突变：

- 外部直接改 `g_motor.iq_ref` / `g_motor.id_ref` 时，命令会原样进入 10 kHz 电流 PI。
- `speed_loop_enable = 0` 的纯电流环测试下，`iq_ref` 本质上就是转矩指令，给自由轴阶跃电流时，电机会立刻产生加速趋势。

原代码里，电流 PI 的参考值没有单独的“应用层缓冲”：

- 原始命令量和真正送进 PI 的量是同一个变量。
- 只要上层单拍改大一点，`uq_ref` 这一拍就可能直接冲到比较高。
- 如果这时编码器角度、反电动势、机械自由转动同时叠加，波形上就容易看到尖峰或短时乱跳。

## 2. 本次新增的抑制措施

本次没有去给电流反馈硬加低通，因为那会直接吃掉带宽，而是改成了“命令整形”：

1. 保留原始命令
   - `g_motor.id_ref`
   - `g_motor.iq_ref`

2. 新增内部应用命令
   - `g_id_ref_applied_a`
   - `g_iq_ref_applied_a`

3. 在每个 10 kHz 快环里，应用命令先经过两步处理再进 PI
   - 有限值检查：`NaN/Inf` 直接清零
   - 电流限幅：限制在 `[-g_motor.iq_limit, +g_motor.iq_limit]`
   - 斜坡限速：按 `PROGRAM_CURRENT_REF_RAMP_A_PER_S = 500 A/s` 推进

对应效果：

- 0.5 A 这种小阶跃仍然是很快的。
- 单拍跳变不会直接把 `uq_ref` 顶满。
- 纯电流模式下，用调试器突然把 `iq_ref` 改大时，转矩建立更平滑，不容易出现电流尖峰和机械抽动同时爆出来。

## 3. 执行位置和频率

| 运算 | 频率 | 执行方式 | 执行位置 |
| --- | --- | --- | --- |
| `program_update_applied_current_references()` | 10 kHz | 直接函数调用 | `ADC1` 注入组完成中断 |
| `program_run_current_loop()` | 10 kHz | 直接函数调用 | `ADC1` 注入组完成中断 |
| 电流参考斜坡更新 | 100 us 一次 | 限速器 | `program_run_current_loop()` 内 |
| 原始命令遥测刷新 | 10 kHz 节拍下同步更新 | 结构体写入 | `program_update_debug_telemetry()` |

## 4. 推荐调试抓取量

建议同时观察下面 6 个量：

- `iq_ref_cmd`
- `iq_ref_applied_cmd`
- `iq`
- `uq_ref_cmd`
- `theta_elec`
- `speed_loop_enable`

判读方法：

- 如果 `iq_ref_cmd` 跳了，但 `iq_ref_applied_cmd` 是平滑上升，说明尖峰已经不是“命令硬阶跃”导致的。
- 如果 `iq_ref_applied_cmd` 很平滑，`iq` 仍然有尖峰，就该继续看采样时刻、相电流零漂、角度抖动或者死区补偿。
- 如果 `speed_loop_enable = 0` 且 `iq_ref_applied_cmd > 0`，电机自由转起来本身是符合物理规律的，不代表电流环出错。

## 5. 建议的调试步骤

1. 先在 `speed_loop_enable = 0` 下做小阶跃
   - 例如 `iq_ref_cmd: 0 -> 0.2 -> 0.5 A`
   - 先不要直接上更大的电流

2. 同时看 `iq_ref_cmd` 和 `iq_ref_applied_cmd`
   - 确认应用命令是否按斜坡推进
   - 如果两者完全重合，说明你看的不是这次新增的遥测变量

3. 观察 `iq` 和 `uq_ref_cmd`
   - 正常情况下，`iq` 应该跟随 `iq_ref_applied_cmd`
   - `uq_ref_cmd` 会有响应，但不应该出现单拍特别高的尖刺

4. 一旦看到异常尖峰，立刻对比 `theta_elec`
   - 如果 `theta_elec` 同拍发生跳变，问题更偏角度链路
   - 如果 `theta_elec` 很平滑，但 `iq` 乱跳，问题更偏采样链路或 PI 参数

5. 再看是否机械自由转动
   - 如果自由轴未锁定，`iq_ref_applied_cmd > 0` 时电机转起来是正常的
   - 想纯看静态电流环，建议锁轴，或者先测 `id` 阶跃

## 6. 这次修改的边界

这次修改主要解决“命令瞬时注入导致的尖峰风险”，还没有做下面这些更激进的处理：

- 不对 `id/iq` 反馈做低通，以免压缩电流环带宽。
- 不对相电流做中值滤波，以免把真实过流也滤掉。
- 不改采样触发点和 PWM 死区配置，这些属于下一层硬件时序优化。

如果你复测后仍然看到尖峰，但 `iq_ref_applied_cmd` 已经很平滑，那么下一步应继续排查：

- 三相电流采样窗口是否卡在开关噪声边沿
- `theta_elec` 是否还存在偶发跳点
- 零电流偏置在热态下是否漂移
- `current_kp/current_ki` 是否对当前母线电压和电机电感偏激

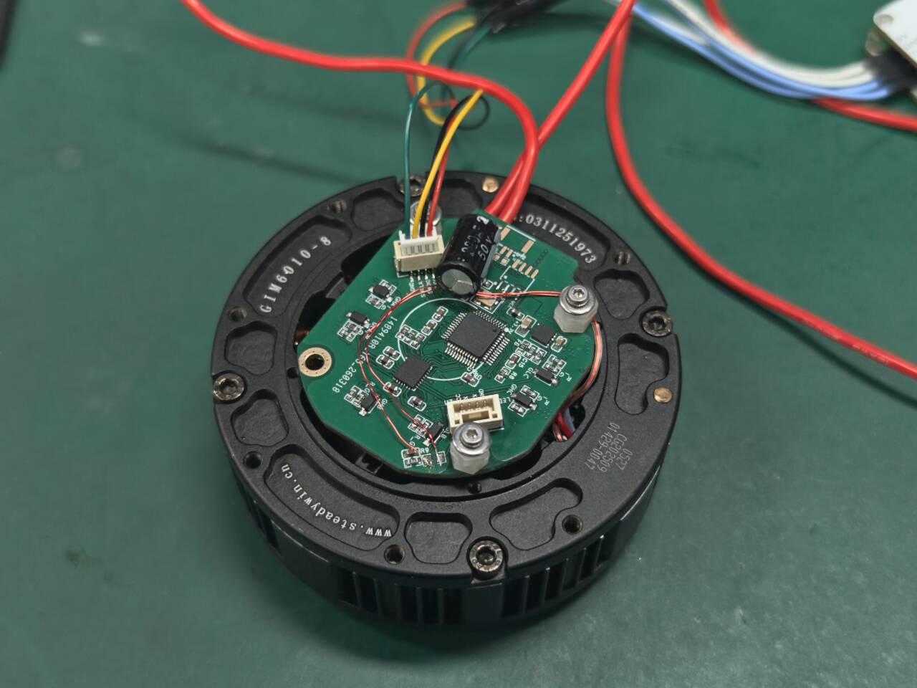
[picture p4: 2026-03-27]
docs/images/placeholder-board-photo.jpg

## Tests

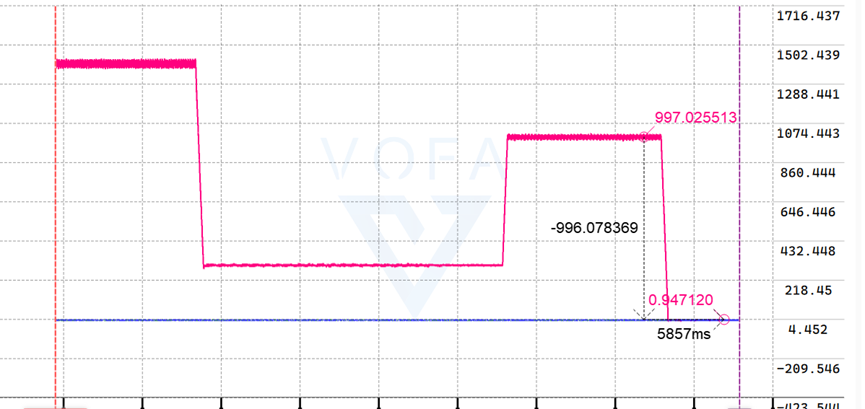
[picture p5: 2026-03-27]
docs/images/SPD_TEST_4.png

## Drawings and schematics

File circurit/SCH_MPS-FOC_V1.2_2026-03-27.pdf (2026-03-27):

高压BUCK 48V->12V | BUCK 12V->5V

PB15 29 PB14 28 PB13 27 PB12 26 PB11 25 PB10 22 PB9 46 PB8-BOOT0 45 PB7 44 PB6 43 PB5 42 PB4 41 PB3 40 PB2 18 PB1 17 PB0 16

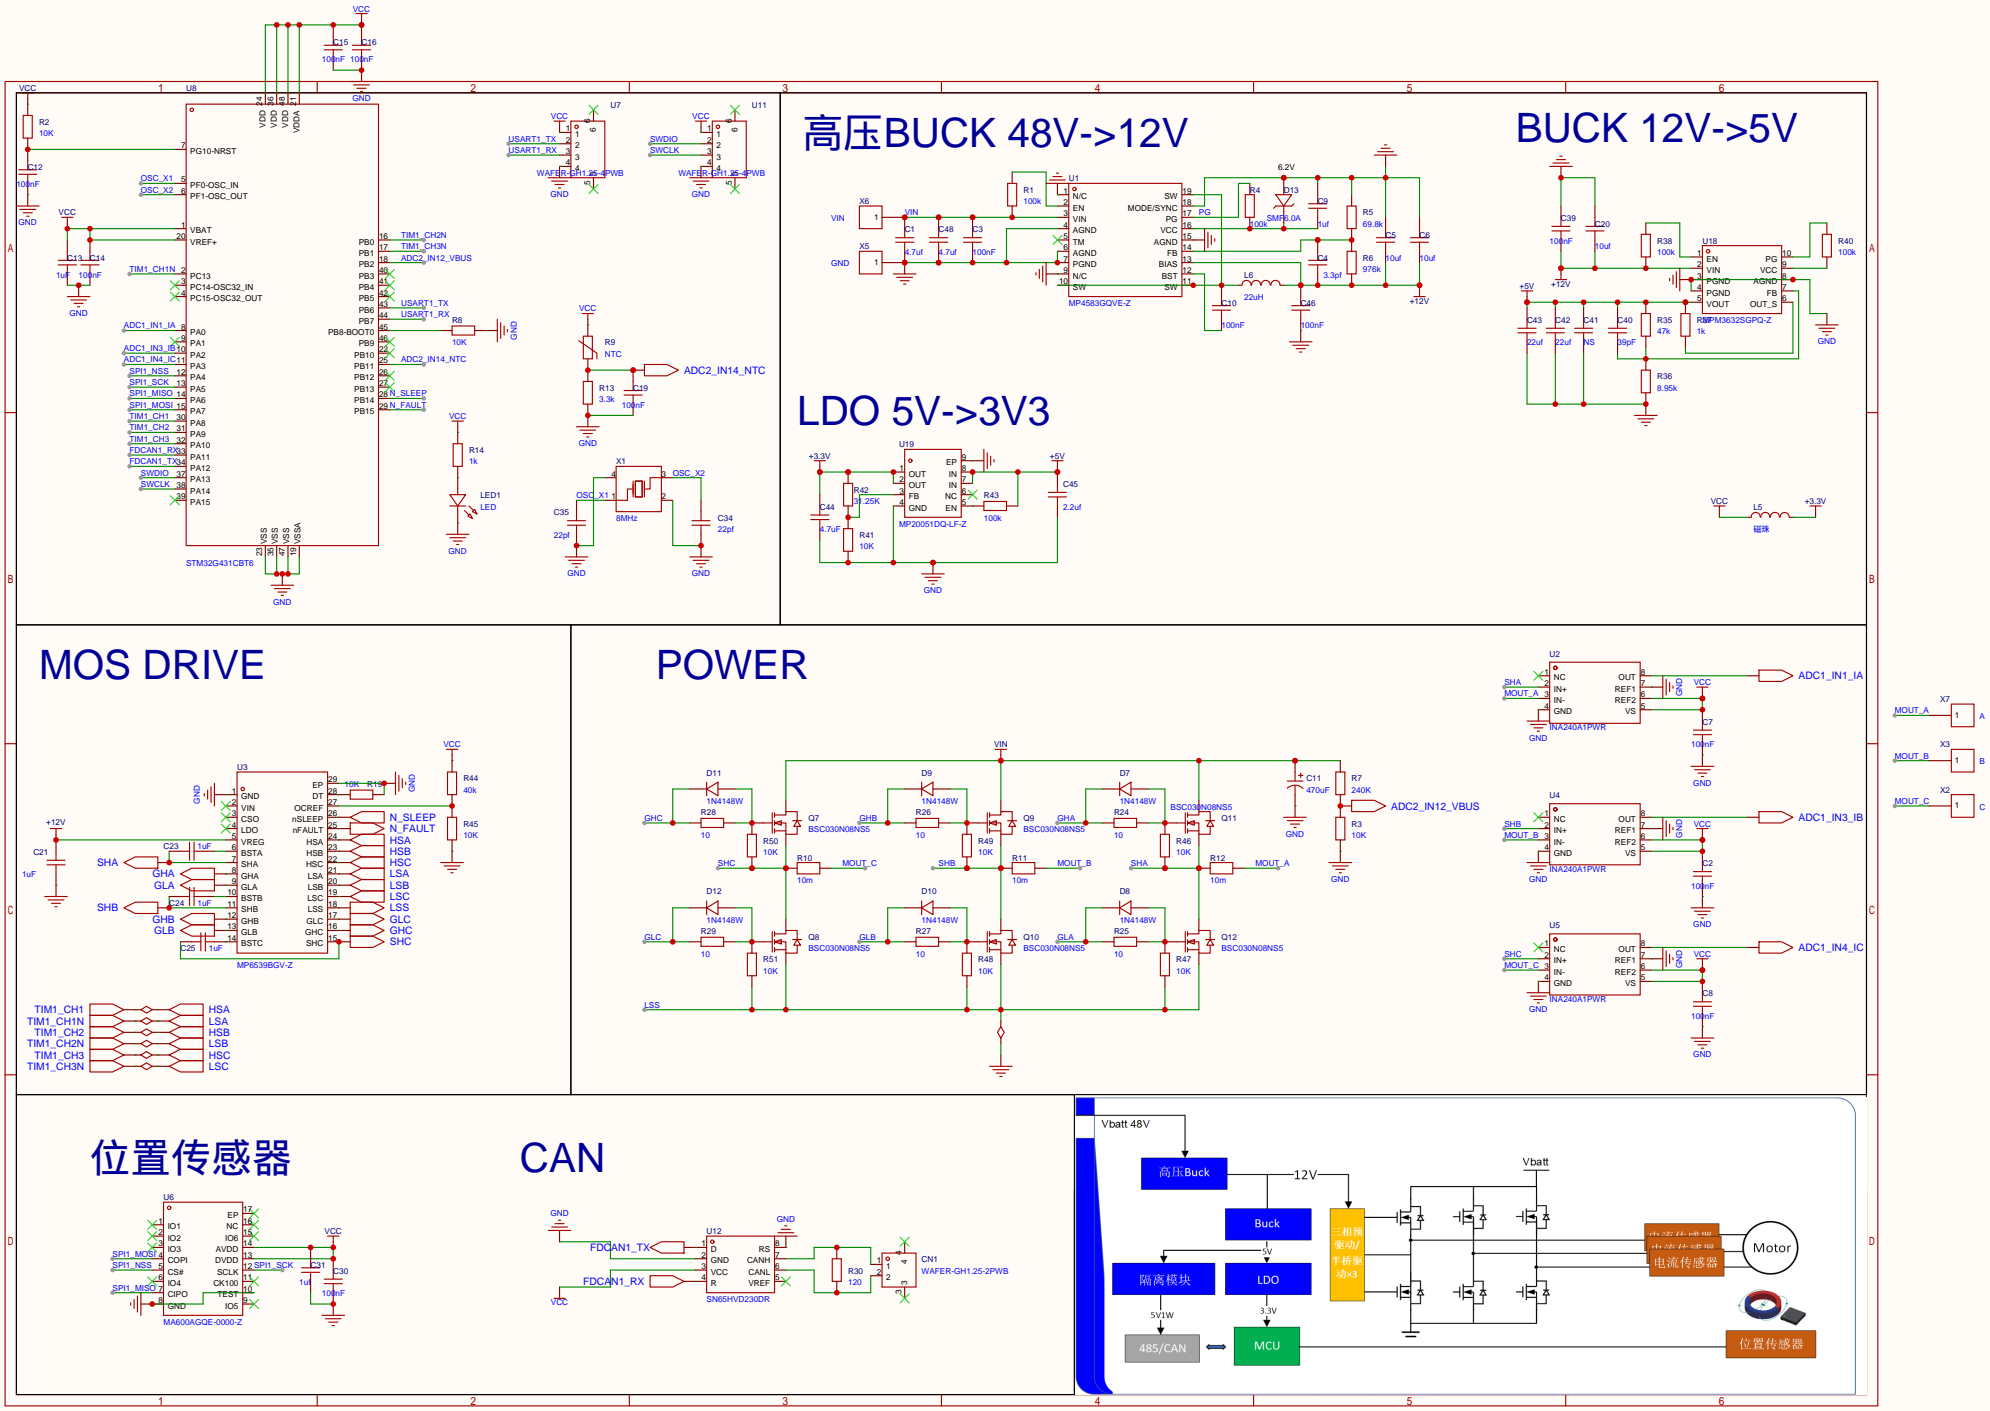
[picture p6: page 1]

TEST 10 CK100 11 SCLK 12 DVDD 13 AVDD 14 IO6 15 NC 16 EP 17

原理图 | MPS-FOC_V1.2 | 创建日期 | 2026-03-18

更新日期 | 2026-03-18

板子 | MPS-FOC-V1.2 | 图页 | P1
绘制 | | MPS-COMPETITION-FOC
审阅

V1.0 | A3 | 嘉立创EDA

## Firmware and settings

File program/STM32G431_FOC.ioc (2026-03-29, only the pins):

Mcu.UserName=STM32G431CBTx
PA0.Signal=ADC1_IN1
PA10.Signal=S_TIM1_CH3
PA11.Signal=FDCAN1_RX
PA12.Signal=FDCAN1_TX
PA13.Signal=SYS_JTMS-SWDIO
PA14.Signal=SYS_JTCK-SWCLK
PA2.Signal=ADC1_IN3
PA3.Signal=ADC1_IN4
PA4.GPIO_Label=ENC_CS
PA4.Signal=GPIO_Output
PA5.Signal=SPI1_SCK
PA6.Signal=SPI1_MISO
PA7.Signal=SPI1_MOSI
PA8.Signal=S_TIM1_CH1
PA9.Signal=S_TIM1_CH2
PB0.Signal=TIM1_CH2N
PB1.Signal=TIM1_CH3N
PB11.Signal=ADC2_IN14
PB14.GPIO_Label=N_SLEEP
PB14.Signal=GPIO_Output
PB15.GPIO_Label=N_FAULT
PB15.Signal=GPIO_Input
PB2.Signal=ADC2_IN12
PB6.Signal=USART1_TX
PB7.Signal=USART1_RX
PC13.Signal=TIM1_CH1N
PF0-OSC_IN.Signal=RCC_OSC_IN
PF1-OSC_OUT.Signal=RCC_OSC_OUT

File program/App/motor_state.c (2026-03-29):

#include "motor_state.h"

#define MOTOR_ALIGN_TIME_MS           300U
#define MOTOR_OPEN_LOOP_TO_CLOSE_MS   1500U
#define MOTOR_OPEN_LOOP_SPEED_ELEC    20.0f
#define MOTOR_ALIGN_UD_V              0.8f
#define MOTOR_OPEN_LOOP_UQ_V          1.0f

/* 函数作用：执行一次状态切换并记录进入时间。
 * 输入：motor 为状态机对象，next_state 为目标状态，now_ms 为当前毫秒时间。
 * 输出：无返回值。
 * 调用频率：仅在发生状态切换时调用。
 * 运行内容：写入新的状态值，并记录状态进入时刻。 */
static void motor_state_enter(motor_state_t *motor, motor_state_id_t next_state, uint32_t now_ms)
{
    motor->state = next_state;
    motor->state_enter_ms = now_ms;
}

/* 函数作用：初始化电机状态机对象。
 * 输入：motor 为待初始化的状态机对象。
 * 输出：无返回值。
 * 调用频率：系统启动时调用一次。
 * 运行内容：设置默认状态、清零运行和故障变量，并初始化速度滤波器和 PI 占位对象。 */
void motor_state_init(motor_state_t *motor)
{
    if (motor == 0) {
        return;
    }

    motor->state = MOTOR_STATE_READY;
    motor->run_request = 0U;
    motor->speed_loop_enable = 1U;
    motor->current_loop_enable = 1U;
    motor->position_loop_enable = 0U;
    motor->control_angle_open_loop_enable = 0U;
    motor->align_done = 0U;
    motor->fault_code = MOTOR_FAULT_NONE;
    motor->state_enter_ms = 0U;
    motor->theta_open_loop = 0.0f;
    motor->open_loop_speed_elec = MOTOR_OPEN_LOOP_SPEED_ELEC;
    motor->control_angle_open_loop_speed_elec = MOTOR_OPEN_LOOP_SPEED_ELEC;
    motor->id_ref = 0.0f;
    motor->iq_ref = 0.0f;
    motor->ud_ref = 0.0f;
    motor->uq_ref = 0.0f;
    motor->speed_ref_mech_rpm = 0.0f;
    motor->speed_ref_mech_rad_s = 0.0f;
    motor->speed_ref_mech_applied_rad_s = 0.0f;
    motor->speed_meas_mech_rad_s = 0.0f;
    motor->speed_ref_elec_rad_s = 0.0f;
    motor->speed_meas_elec_rad_s = 0.0f;
    motor->speed_kp = 0.001f;
    motor->speed_ki = 0.004f;
    motor->position_ref_mech_deg = 0.0f;
    motor->position_ref_mech_rad = 0.0f;
    motor->position_meas_mech_deg = 0.0f;
    motor->position_meas_mech_rad = 0.0f;
    motor->position_error_mech_deg = 0.0f;
    motor->position_error_mech_rad = 0.0f;
    motor->position_kp = 8.0f;
    motor->position_ki = 0.0f;
    motor->position_kd = 0.0f;
    motor->position_integral_speed = 0.0f;
    motor->position_speed_limit_mech_rad_s = 20.0f;
    motor->speed_meas_lpf_cutoff_hz = 150.0f;
    motor->speed_integral_iq = 0.0f;
    motor->speed_integral_uq = 0.0f;
    motor->iq_limit = 2.0f;
    motor->current_kp = 0.5f;
    motor->current_ki = 200.0f;
    motor->id_integral_v = 0.0f;
    motor->iq_integral_v = 0.0f;
    motor->voltage_limit = 0.0f;

    filter_lpf_f32_init(&motor->speed_lpf, 0.1f, 0.0f);
    drv_pid_pi_init(&motor->speed_pi, 0, 0, -1000, 1000, 0);
}

/* 函数作用：执行一次电机状态机。
 * 输入：motor 为状态机对象，foc 为 FOC 核心对象，now_ms 为当前毫秒时间。
 * 输出：无返回值，状态变化和 FOC 输出直接写回对象。
 * 调用频率：当前由 program_task() 按约 1 kHz 调用。
 * 运行内容：处理 READY、ALIGN、OPEN_LOOP、CLOSED_LOOP、FAULT 各状态逻辑，并给 FOC 下发对应电压命令。 */
void motor_state_task(motor_state_t *motor, foc_core_t *foc, uint32_t now_ms)
{
    float elapsed_s;

    if ((motor == 0) || (foc == 0)) {
        return;
    }

    if (motor->fault_code != MOTOR_FAULT_NONE) {
        motor_state_enter(motor, MOTOR_STATE_FAULT, now_ms);
    }

    switch (motor->state) {
    case MOTOR_STATE_READY:
        foc_core_reset_output(foc);
        if (motor->run_request != 0U) {
            motor->align_done = 0U;
            motor_state_enter(motor, MOTOR_STATE_ALIGN, now_ms);
        }
        break;

    case MOTOR_STATE_ALIGN:
        /* 对齐阶段先固定电角度，建立转子零位参考。 */
        motor->theta_open_loop = 0.0f;
        motor->ud_ref = MOTOR_ALIGN_UD_V;
        motor->uq_ref = 0.0f;
        foc_core_run_voltage_open_loop(foc, motor->ud_ref, motor->uq_ref, motor->theta_open_loop, foc->vbus);

        if ((now_ms - motor->state_enter_ms) >= MOTOR_ALIGN_TIME_MS) {
            motor->align_done = 1U;
            motor_state_enter(motor, MOTOR_STATE_OPEN_LOOP, now_ms);
        }
        break;

    case MOTOR_STATE_OPEN_LOOP:
        elapsed_s = 0.001f * (float)(now_ms - motor->state_enter_ms);
        motor->theta_open_loop = elapsed_s * motor->open_loop_speed_elec;
        motor->ud_ref = 0.0f;
        motor->uq_ref = MOTOR_OPEN_LOOP_UQ_V;
        foc_core_run_voltage_open_loop(foc, motor->ud_ref, motor->uq_ref, motor->theta_open_loop, foc->vbus);

        if (motor->run_request == 0U) {
            motor_state_enter(motor, MOTOR_STATE_READY, now_ms);
        } else if ((now_ms - motor->state_enter_ms) >= MOTOR_OPEN_LOOP_TO_CLOSE_MS) {
            motor_state_enter(motor, MOTOR_STATE_CLOSED_LOOP, now_ms);
        }
        break;

    case MOTOR_STATE_CLOSED_LOOP:
        /* 当前位置先保留一个最小闭环占位，后续接电流环和速度环。 */
        motor->theta_open_loop += 0.001f * motor->open_loop_speed_elec;
        motor->ud_ref = 0.0f;
        motor->uq_ref = MOTOR_OPEN_LOOP_UQ_V;
        foc_core_run_voltage_open_loop(foc, motor->ud_ref, motor->uq_ref, motor->theta_open_loop, foc->vbus);

        if (motor->run_request == 0U) {
            motor_state_enter(motor, MOTOR_STATE_READY, now_ms);
        }
        break;

    case MOTOR_STATE_FAULT:
        foc_core_reset_output(foc);
        if ((motor->run_request == 0U) && (motor->fault_code == MOTOR_FAULT_NONE)) {
            motor_state_enter(motor, MOTOR_STATE_READY, now_ms);
        }
        break;

    case MOTOR_STATE_INIT:
    default:
        motor_state_enter(motor, MOTOR_STATE_READY, now_ms);
        break;
    }
}

/* 函数作用：设置运行请求标志。
 * 输入：motor 为状态机对象，enable 为 0 或 1。
 * 输出：无返回值。
 * 调用频率：外部控制逻辑按需调用。
 * 运行内容：只更新运行请求，真正的状态切换在 motor_state_task() 里完成。 */
void motor_state_set_run_request(motor_state_t *motor, uint8_t enable)
{
    if (motor == 0) {
        return;
    }

    motor->run_request = enable;
}

/* 函数作用：设置故障码。
 * 输入：motor 为状态机对象，fault_code 为故障类型。
 * 输出：无返回值。
 * 调用频率：检测到故障条件时按需调用。
 * 运行内容：写入故障码，状态机会在下一拍进入 FAULT。 */
void motor_state_set_fault(motor_state_t *motor, uint8_t fault_code)
{
    if (motor == 0) {
        return;
    }

    motor->fault_code = fault_code;
}

/* 函数作用：清除故障码。
 * 输入：motor 为状态机对象。
 * 输出：无返回值。
 * 调用频率：确认故障解除后按需调用。
 * 运行内容：把故障码恢复为 NONE，允许状态机回到 READY。 */
void motor_state_clear_fault(motor_state_t *motor)
{
    if (motor == 0) {
        return;
    }

    motor->fault_code = MOTOR_FAULT_NONE;
}

/* 函数作用：把状态枚举转换成可读字符串。
 * 输入：state 为状态枚举值。
 * 输出：返回状态名字符串常量指针。
 * 调用频率：调试打印时按需调用。
 * 运行内容：提供串口、上位机或日志需要的可读状态名。 */
const char *motor_state_get_name(motor_state_id_t state)
{
    switch (state) {
    case MOTOR_STATE_INIT:
        return "INIT";
    case MOTOR_STATE_READY:
        return "READY";
    case MOTOR_STATE_ALIGN:
        return "ALIGN";
    case MOTOR_STATE_OPEN_LOOP:
        return "OPEN_LOOP";
    case MOTOR_STATE_CLOSED_LOOP:
        return "CLOSED_LOOP";
    case MOTOR_STATE_FAULT:
        return "FAULT";
    default:
        return "UNKNOWN";
    }
}

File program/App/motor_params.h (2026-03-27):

#ifndef MOTOR_PARAMS_H
#define MOTOR_PARAMS_H

#include <math.h>

#define MOTOR_POLE_PAIRS         14.0f
#define MOTOR_GEAR_RATIO         8.0f
#define MOTOR_ENCODER_ON_OUTPUT_SHAFT 0U
#define MOTOR_ENCODER_DIRECTION_SIGN (-1.0f)
#define MOTOR_TWO_PI             6.28318530718f

static inline float motor_params_wrap_angle_rad(float angle_rad)
{
    float turns;

    if (!isfinite(angle_rad)) {
        return 0.0f;
    }

    turns = floorf(angle_rad / MOTOR_TWO_PI);
    angle_rad -= turns * MOTOR_TWO_PI;

    if (angle_rad < 0.0f) {
        angle_rad += MOTOR_TWO_PI;
    } else if (angle_rad >= MOTOR_TWO_PI) {
        angle_rad -= MOTOR_TWO_PI;
    }

    return angle_rad;
}

static inline float motor_params_rotor_mech_to_elec_rad(float rotor_mech_angle_rad)
{
    return motor_params_wrap_angle_rad(rotor_mech_angle_rad * MOTOR_POLE_PAIRS);
}

static inline float motor_params_encoder_mech_to_rotor_mech_rad(float encoder_mech_angle_rad)
{
#if MOTOR_ENCODER_ON_OUTPUT_SHAFT
    return encoder_mech_angle_rad * MOTOR_ENCODER_DIRECTION_SIGN * MOTOR_GEAR_RATIO;
#else
    return encoder_mech_angle_rad * MOTOR_ENCODER_DIRECTION_SIGN;
#endif
}

static inline float motor_params_encoder_speed_to_rotor_speed(float encoder_speed_rad_s)
{
#if MOTOR_ENCODER_ON_OUTPUT_SHAFT
    return encoder_speed_rad_s * MOTOR_ENCODER_DIRECTION_SIGN * MOTOR_GEAR_RATIO;
#else
    return encoder_speed_rad_s * MOTOR_ENCODER_DIRECTION_SIGN;
#endif
}

static inline float motor_params_rotor_speed_to_output_speed(float rotor_speed_rad_s)
{
    return rotor_speed_rad_s / MOTOR_GEAR_RATIO;
}

#endif /* MOTOR_PARAMS_H */

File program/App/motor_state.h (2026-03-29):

#ifndef MOTOR_STATE_H
#define MOTOR_STATE_H

#include <stdint.h>

#include "drv_pid.h"
#include "filter.h"
#include "foc_core.h"

typedef enum
{
    MOTOR_STATE_INIT = 0,
    MOTOR_STATE_READY,
    MOTOR_STATE_ALIGN,
    MOTOR_STATE_OPEN_LOOP,
    MOTOR_STATE_CLOSED_LOOP,
    MOTOR_STATE_FAULT
} motor_state_id_t;

typedef enum
{
    MOTOR_FAULT_NONE = 0,
    MOTOR_FAULT_DRIVER = 1,
    MOTOR_FAULT_OVERVOLTAGE = 2
} motor_fault_t;

typedef struct
{
    motor_state_id_t state;
    uint8_t run_request;
    uint8_t speed_loop_enable;
    uint8_t current_loop_enable;
    uint8_t position_loop_enable;
    uint8_t control_angle_open_loop_enable;
    uint8_t align_done;
    uint8_t fault_code;
    uint32_t state_enter_ms;
    float theta_open_loop;
    float open_loop_speed_elec;
    float control_angle_open_loop_speed_elec;
    float id_ref;
    float iq_ref;
    float ud_ref;
    float uq_ref;
    float speed_ref_mech_rpm;
    float speed_ref_mech_rad_s;
    float speed_ref_mech_applied_rad_s;
    float speed_meas_mech_rad_s;
    float speed_ref_elec_rad_s;
    float speed_meas_elec_rad_s;
    float speed_kp;
    float speed_ki;
    float position_ref_mech_deg;
    float position_ref_mech_rad;
    float position_meas_mech_deg;
    float position_meas_mech_rad;
    float position_error_mech_deg;
    float position_error_mech_rad;
    float position_kp;
    float position_ki;
    float position_kd;
    float position_integral_speed;
    float position_speed_limit_mech_rad_s;
    float speed_meas_lpf_cutoff_hz;
    float speed_integral_iq;
    float speed_integral_uq;
    float iq_limit;
    float current_kp;
    float current_ki;
    float id_integral_v;
    float iq_integral_v;
    float voltage_limit;
    filter_lpf_f32_t speed_lpf;
    drv_pid_pi_t speed_pi;
} motor_state_t;

void motor_state_init(motor_state_t *motor);
void motor_state_task(motor_state_t *motor, foc_core_t *foc, uint32_t now_ms);
void motor_state_set_run_request(motor_state_t *motor, uint8_t enable);
void motor_state_set_fault(motor_state_t *motor, uint8_t fault_code);
void motor_state_clear_fault(motor_state_t *motor);
const char *motor_state_get_name(motor_state_id_t state);

#endif /* MOTOR_STATE_H */

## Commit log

2026-03-27 Initial import of MPS FOC STM32G431 project
    [Drill_PTH_Through.DRL, Drill_PTH_Through_Via.DRL, Gerber_BoardOutlineLayer.GKO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]
2026-03-29 Update project docs and experiment files
    - Add GPL 3.0 LICENSE file
    - Fix README section numbering (5/6/7/8/9/10)
    - Add license section to README
    - Update hardware config table with MPS chips (MP6539B, MP4583, MIE1W0505, MPM3632S, MP20051)
    - Add experiment video files (LoadTEST, Test1-4)
    - Update program source files (ma600a, motor_state, program, spi, ioc)
    [STM32G431_FOC.ioc, motor_state.c, motor_state.h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]
2026-03-31 Update motor control implementation
2026-03-31 Add motor control accuracy charts
2026-03-31 Update poster and presentation materials
2026-04-13 Add debug PWM test docs and tune position hold
2026-09-11 Restructure repository for V1.3 and rewrite documentation
    Hardware and assets: refresh 3dmodel, replace circurit with the V1.3 EDA project/Gerber/netlist, split datasheet out, and move README images into figure/ instead of docs/images and docs/figures. The experiment and manufacture trees are dropped.
    Firmware: replace drv_pid/motor_state/motor_params with motor_ctrl, board, units and app_config, and expose the g_cmd/g_fb interface from motor.h.
    Docs: rewrite README and docs/quick-start.md against the V1.3 code and hardware, regenerate docs/适配新电机标准流程.docx around the CFG_* parameters, and fix all file and image references.
2026-09-15 Backup working motor tuning before serial desktop controller
2026-11-02 Add serial host controller and 16 A current range
    Firmware:
    - New host_link.c/h: FOC Serial v4 framing (CRC-16/CCITT-FALSE), HELLO/CONFIG/RUN/STOP/CLEAR/PING/READ/RATE,
    range-checked CONFIG, bandwidth-to-PI conversion, 2 s link timeout for remote-started runs.
    - cli_uart: RX ring buffer fed from the UART interrupt, DMA TX queue; JustFloat stays the power-on default
    until HELLO switches to the framed protocol.
    - Current sensing: 8 mOhm || 10 mOhm = 4.44 mOhm shunt, 16 A software/OC limit, 1500 Hz dq current LPF,
    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
2026-11-03 Switch shunt to 4 mOhm and tighten documentation
    Firmware and host:
    - CFG_SHUNT_OHM changed from 8 mOhm || 10 mOhm (4.444 mOhm) to a single 4 mOhm shunt:
    0.08 V/A, full scale +-20.625 A, 0.010073260 A/count. 16 A software limit keeps
    ~22% headroom. Harness assertions updated; 49 host tests pass.
    - board.c comment and both sample-chain sections of the docs updated to match.
    Docs:
    - Section 8 rewritten around the serial host app: connect, self-check, PWM test,
    three-loop tuning, with screenshots and scope captures taken from the video script.
    - Section 6.2 sampling chain and 6.4 loop bandwidths aligned with app_config.h
    (4 mOhm, 250/10/2 Hz, 150 Hz speed LPF, 16 A limits).
    - 6.1 fast-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
